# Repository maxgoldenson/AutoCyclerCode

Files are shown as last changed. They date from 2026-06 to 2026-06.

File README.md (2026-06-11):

# AutoCycler

Automated coffee-machine cycler for endurance testing. A Raspberry Pi runs a touchscreen
GUI that drives two ESP32 boards over USB — a **dispenser** (stepper that doses coffee)
and a **front assembly** (color sensors + servo + brew trigger) — to run brew cycles
unattended. The whole stack (Pi app, launcher, and ESP32 firmware) **updates itself
over-the-air from GitHub** — you set a Pi up once, then just push to `main`.

---

## 1. Set up a Pi — one command

On a fresh Raspberry Pi (logged in as your normal user, connected to the internet), open
a Terminal and paste:

```bash
curl -fsSL https://raw.githubusercontent.com/maxgoldenson/AutoCyclerCode/main/pi_install.sh | bash && sudo reboot
```

That installs everything (Python GUI, the ESP32 flashing toolchain, serial access),
deploys the app + launcher + firmware, sets it to start on boot, prints a green
checklist, and reboots. **Plug both ESP32 boards into USB** (before or after — it waits
for them).

After the reboot the app appears, connects to the boards, and flashes them to the latest
firmware automatically (you'll see a live progress screen). That's the whole setup.

> The script is safe to re-run. It works on Raspberry Pi OS Bullseye, Buster, and
> Bookworm. If any line in the checklist shows `[!!]`, just run it again — it's almost
> always a flaky download.

---

## 2. It updates itself

Once a Pi is set up, it polls GitHub (`main`) every minute and updates **on its own** —
you never have to touch the Pi again:

| What | When it updates |
|---|---|
| **App** (`coffee_cycler.py`) | a new version is on `main` → downloads, restarts the app |
| **Launcher** itself | `launcher.py` changed → self-updates and relaunches |
| **ESP32 firmware** | a board's `FW_VERSION` changed → compiles + flashes it (live progress screen), then **reboots the Pi** to bring the board up on the new firmware (the version is recorded first, so it won't loop) |

**Updates never interrupt a running brew series.** While the app is running cycles it
raises a "busy" flag; the launcher defers *all* updates (app, firmware, and the reboot)
until the series finishes, then applies them. If the app crashes mid-run the flag goes
stale and updates resume on their own.

---

## 3. Releasing an update (maintainer)

Everything flows from `main`:

- **App change:** edit `coffee_cycler.py`, push to `main`. Pis pick it up within a minute.
- **Firmware change:** edit the `.ino`, **bump its `#define FW_VERSION`**, push to `main`.
  Pis flash it on the next check.
  - ⚠️ If you change firmware behaviour but *don't* bump `FW_VERSION`, the fleet won't
    flash it. This is intentional — it stops comment/whitespace edits from re-flashing
    every Pi. Bump the version whenever the firmware functionally changes.

`FW_VERSION` lives near the top of each sketch (next to `DEVICE_ID`).

---

## 4. Check what's running

The app header shows all three versions at a glance:

```
BrewBird Auto Cycler   v2026-06-11 16:04   ESP32 fw — DISP 2026-06-10.4 · FRONT 2026-06-10.3
```

Or on the Pi:

```bash
grep '^VERSION' ~/autocycler/coffee_cycler.py    # app version (the GUI header)
cat ~/autocycler/flashed_firmware.json           # firmware version flashed to each board
tail -f ~/autocycler/launcher.log                # live: what the launcher is doing
```

---

## 5. Updating Pis set up before self-update existed (one-time)

Older Pis run a launcher that can't self-update. Bring each one onto the self-updating
launcher **once** — after this it's automatic forever:

```bash
cd ~/autocycler && ok=1; for f in launcher.py bootscript.py flash_splash.py; do curl -fsSL "https://raw.githubusercontent.com/maxgoldenson/AutoCyclerCode/main/$f" -o "/tmp/$f" || ok=0; done; if [ "$ok" = 1 ] && grep -q 'def self_update' /tmp/launcher.py; then mv /tmp/launcher.py /tmp/bootscript.py /tmp/flash_splash.py . && echo "OK — rebooting" && sudo reboot; else echo "FAILED — nothing changed"; fi
```

(Or just re-run the Section 1 installer — it's idempotent.)

---

## 6. Troubleshooting

```bash
tail -30 ~/autocycler/launcher.log     # the launcher logs every decision here
uptime; ps -o pid,etime,cmd -C python3 # is it stable? (not a reboot loop)
```

| Symptom | Likely cause / fix |
|---|---|
| App never updates | No internet, or an old pre-self-update launcher (do Section 5). |
| `version 'GLIBC_2.34' not found` when flashing | ESP32 core 3.x on old Pi OS — the installer pins `esp32:esp32@2.0.17`; re-run it. |
| Board won't connect / `device reports readiness… returned no data` | ModemManager grabbing the port — the installer disables it; re-run it. |
| Header shows `ESP32 fw … ?` for a board | That board is on old firmware without the version query; it updates on the next flash. |
| "Keeps flashing every few minutes" | Either a real `FW_VERSION` bump (one flash, then stops) or an upload is failing — the log line `… needs flashing: version X (on board: Y)` shows which. |
| Screen reboots right after a firmware flash | Expected — the Pi auto-reboots after flashing to reliably bring the boards back online. It records the version first, so it won't loop. (Needs passwordless `sudo`, the Pi default.) |

---

## 7. What's in the repo

| File | Role |
|---|---|
| `coffee_cycler.py` | The Tkinter touchscreen app (runs the brew cycles). |
| `launcher.py` | Boot supervisor: self-update, app update, firmware flashing, app lifecycle. |
| `AUTOCYCLER_DISPENSOR/*.ino` | Dispenser ESP32 firmware (stepper + dispense protocol). |
| `AUTOCYCLER_FRONT/*.ino` | Front-assembly ESP32 firmware (sensors, servo, brew trigger). |
| `flash_splash.py` | Live "updating firmware" progress screen. |
| `bootscript.py` | Thin autostart shim that execs the launcher. |
| `pi_install.sh` | The one-shot installer (Section 1). |
| `PI_SETUP.md` | Detailed/manual setup reference. |
| `.claude/skills/ota/SKILL.md` | OTA system design, operational rules, and gotchas. |

For the OTA architecture and the hard-won gotchas (core pin, ModemManager, onboard-UART,
single-instance, post-flash reset), see `.claude/skills/ota/SKILL.md`.

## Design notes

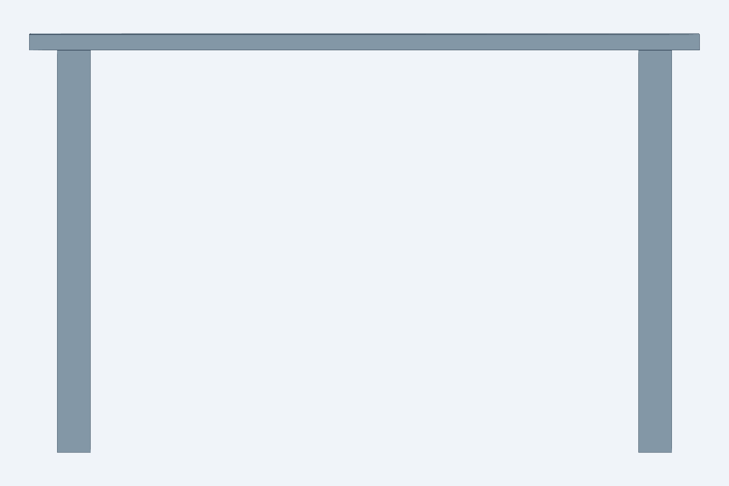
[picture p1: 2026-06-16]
cad/table_front_20260616T002230Z.png

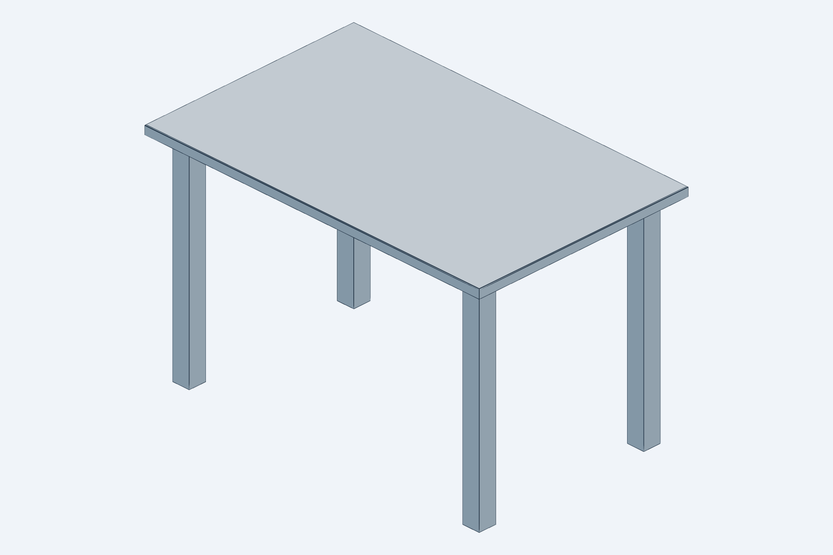
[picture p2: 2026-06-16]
cad/simple_table_20260616T001931Z.png

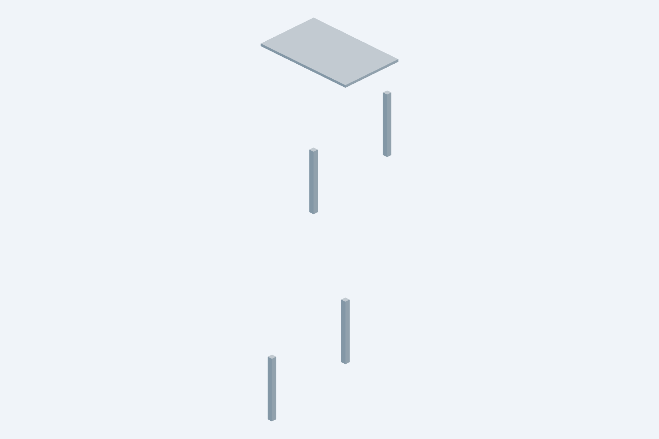
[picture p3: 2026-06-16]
cad/table_exploded_20260616T002232Z.png

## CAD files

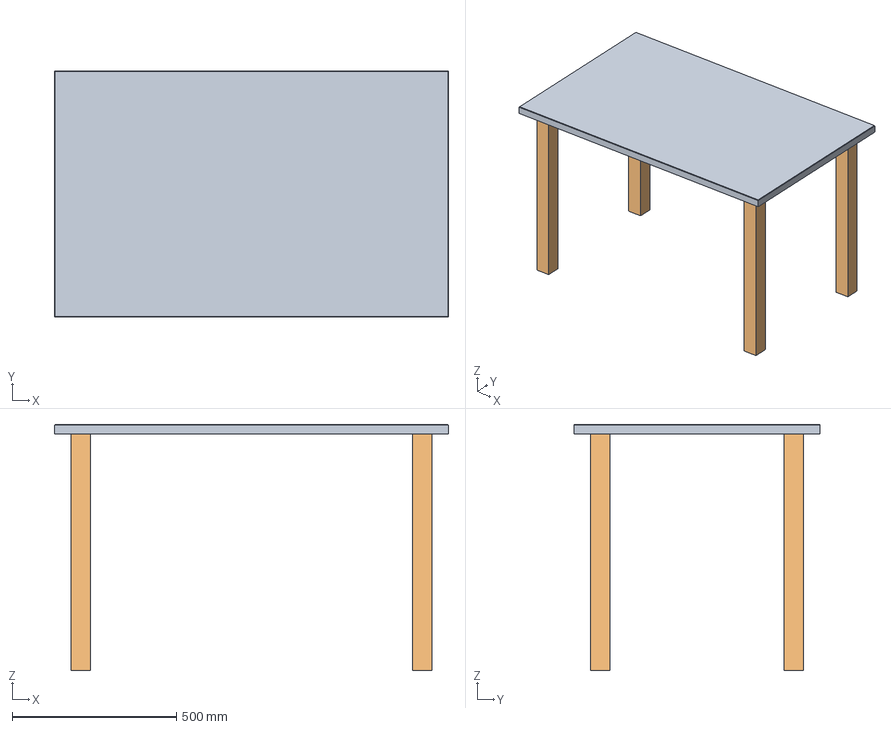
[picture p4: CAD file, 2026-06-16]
cad/simple_table.step
1200.0 x 750.0 x 750.0 mm
tabletop
leg:front_left
leg:front_right
leg:rear_left
leg:rear_right

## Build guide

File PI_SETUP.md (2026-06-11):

# Pi deployment guide — detailed reference

> **New here? Start with [README.md](README.md)** — it has the one-command setup and the
> day-to-day usage. This file is the detailed / manual reference and troubleshooting deep-dive.

## Quick install (recommended)

One script does everything below — toolchain, libraries, code, autostart. Run it on the
Pi as your normal user:

```bash
curl -fsSL https://raw.githubusercontent.com/maxgoldenson/AutoCyclerCode/main/pi_install.sh | bash
sudo reboot
```

It is safe to re-run. Override defaults with env vars, e.g.
`AUTOCYCLER_BRANCH=main ESP32_FQBN=esp32:esp32:esp32doit-devkit-v1 bash pi_install.sh`.
The manual steps below are kept for reference / troubleshooting.

### What it handles for partial / missing devices
- The app UI comes up first and **auto-reconnects** as boards are plugged in — works with
  two, one, or zero modules connected at boot.
- Firmware is flashed **only for boards that are actually connected**. If a module isn't
  plugged in, the launcher waits and flashes it automatically once you connect it.
- A full-screen **"Updating firmware — please wait"** message shows during flashing.

---

This covers the one-time changes on the Raspberry Pi to run the new `launcher.py`
(minute-poll app auto-update + over-the-air ESP32 firmware flashing).

> **Key fact:** `launcher.py` updates `coffee_cycler.py` and the ESP32 firmware, but it
> **does not update itself**. So `launcher.py` and `bootscript.py` must be deployed by
> hand once (Step 1). After that, app and firmware updates are automatic.

Assumes the install lives at `/home/pi/autocycler/` (the default `AUTOCYCLER_DIR`). If
yours is elsewhere, substitute that path and set `AUTOCYCLER_DIR` in the boot env.

---

## Step 1 — Put the new launcher on the Pi

The Pi will poll the **`main`** branch (already baked into the
default; see Step 2 to change it).

```bash
cd /home/pi/autocycler
BRANCH=main
RAW="https://raw.githubusercontent.com/maxgoldenson/AutoCyclerCode/${BRANCH}"

curl -fsSL "${RAW}/launcher.py"   -o launcher.py
curl -fsSL "${RAW}/bootscript.py" -o bootscript.py
```

That's the only manual code copy. On the next boot the launcher will fetch the latest
`coffee_cycler.py` and both `.ino` sketches itself.

---

## Step 2 — Confirm the branch being polled

The default is the feature branch. You don't need to do anything unless you want a
different branch — override it without editing code via an env var:

```bash
# Poll a different branch (e.g. main, once this work is merged):
export AUTOCYCLER_BRANCH=main
```

Set this in the same place your boot launches `launcher.py` (see Step 6) so it persists.
Quick check that the branch is reachable:

```bash
curl -fsS -o /dev/null -w "%{http_code}\n" \
  "https://raw.githubusercontent.com/maxgoldenson/AutoCyclerCode/main/coffee_cycler.py"
# expect: 200
```

---

## Step 3 — Install arduino-cli + ESP32 toolchain (for firmware flashing)

Without this, the app auto-update still works; firmware flashing is just skipped and
retried each minute until the toolchain is present (you'll see a warning in the log).

```bash
# 3a. Install arduino-cli (ARM build auto-detected) straight onto PATH.
# NOTE: the installer drops the binary in ./bin of the CURRENT directory unless you
# set BINDIR — so we force /usr/local/bin to avoid PATH surprises.
curl -fsSL https://raw.githubusercontent.com/arduino/arduino-cli/master/install.sh | sudo BINDIR=/usr/local/bin sh
arduino-cli version    # sanity check (expect 1.5.x)

# If you already ran the installer without BINDIR, the binary is in ./bin of wherever
# you ran it (e.g. /home/pi/autocycler/bin). Just move it onto PATH instead:
#   sudo mv /home/pi/autocycler/bin/arduino-cli /usr/local/bin/

# 3b. Add the ESP32 board package and install the core.
arduino-cli config init
arduino-cli config add board_manager.additional_urls \
  https://espressif.github.io/arduino-esp32/package_esp32_index.json
arduino-cli core update-index

# IMPORTANT — pick the core version for your OS:
#   Raspberry Pi OS Bookworm (glibc >= 2.34): the latest core 3.x works:
#       arduino-cli core install esp32:esp32
#   Raspberry Pi OS Bullseye / Buster (glibc 2.31 / 2.28): the esptool bundled with
#   core 3.x is a frozen binary that needs GLIBC_2.33/2.34 and will fail with
#   "version `GLIBC_2.34' not found". Pin the 2.0.x line, which ships esptool.py as a
#   plain Python script and runs on the Pi's own Python:
#       arduino-cli core install esp32:esp32@2.0.17
# Check your glibc with:  ldd --version | head -1
arduino-cli core install esp32:esp32@2.0.17

# 3c. Install the two libraries the FRONT sketch needs (deps pulled automatically)
arduino-cli lib install "Adafruit TCS34725"
arduino-cli lib install "ESP32Servo"
```

> If your boot process runs `launcher.py` with a minimal `PATH` (e.g. a bare systemd
> unit), either keep `arduino-cli` in `/usr/local/bin` (usually on PATH) or set
> `ARDUINO_CLI=/usr/local/bin/arduino-cli` in the boot env.

---

## Step 4 — Set the board type (FQBN) if needed

The default is the generic `esp32:esp32:esp32`. If your boards are a specific variant,
flashing may fail until you set the right FQBN.

```bash
arduino-cli board listall | grep -i esp32      # find your board's FQBN
# then, in the boot env:
export ESP32_FQBN=esp32:esp32:esp32doit-devkit-v1   # example — use yours
```

---

## Step 5 — Serial port access

The user that runs the launcher must be able to open the ESP32 serial ports (for
WHO-AM-I probing, flashing, and the app itself):

```bash
sudo usermod -aG dialout pi
# log out / back in (or reboot) for the group change to take effect
```

---

## Step 6 — Make the env vars stick, then reboot

Put any `AUTOCYCLER_BRANCH` / `ESP32_FQBN` / `ARDUINO_CLI` overrides where the boot
actually launches `launcher.py`:

- **systemd unit:** add `Environment=AUTOCYCLER_BRANCH=...` lines under `[Service]`,
  then `sudo systemctl daemon-reload`.
- **LXDE autostart / `.bashrc` / `rc.local`:** `export VAR=...` before the
  `python3 .../launcher.py` line.

Then:

```bash
sudo reboot
```

---

## Verify it's working

```bash
tail -f /home/pi/autocycler/launcher.log
```

Expected on first boot:
- `Network ready.`
- `Downloaded new coffee_cycler.py (...)` (if newer than local)
- `Downloaded new firmware source for DISPENSER/FRONT_ASSEMBLY (...)`
- `Identified DISPENSER on /dev/ttyUSB...`, `Compiling ...`, `Uploading ...`,
  `Flashed ... successfully`
- `Launching app.`

Then once a minute it re-checks GitHub and logs only when something changes.

---

## Behaviour notes

- **First boot flashes both ESP32s.** With no flash record yet
  (`flashed_firmware.json` absent), both boards are flashed to the branch's current
  firmware to establish a known-good baseline. After that, only genuine firmware
  changes flash.
- **Failed/skipped flashes retry.** Flashing is gated on a "last successfully flashed"
  record, so a missing toolchain, missing port, or bad compile is retried next cycle —
  it won't silently leave the boards on stale firmware.
- **Updates apply immediately, even mid-cycle.** A new app version restarts the app at
  once; new firmware stops the app, flashes, and restarts. If an update lands during a
  brew it will interrupt that brew. This is safe-ish now (the firmware auto-releases the
  CAP trigger and the dispense is at-most-once), but if you'd rather updates wait for an
  idle moment, that needs a small "busy" signal from the app — ask and it can be added.
- **`launcher.py`/`bootscript.py` don't self-update.** Re-run Step 1 whenever those two
  files change upstream.
- **Switching to `main` after merge:** set `AUTOCYCLER_BRANCH=main` (Step 2/6) and
  re-run Step 1 to pull the merged launcher.

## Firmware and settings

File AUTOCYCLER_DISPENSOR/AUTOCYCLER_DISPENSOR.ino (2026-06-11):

#include <Arduino.h>

// ── Pin config ─────────────────────────────────────────────────────────────────
#define STEP_PIN    25
#define DIR_PIN     33
#define ENABLE_PIN  32

// ── Serial config ──────────────────────────────────────────────────────────────
#define SERIAL_BAUD 115200

// ── Device identity ────────────────────────────────────────────────────────────
#define DEVICE_ID   "DISPENSER"

// ── Firmware version ───────────────────────────────────────────────────────────
// The launcher flashes the board ONLY when this string changes — so editing comments
// or whitespace never triggers a fleet-wide re-flash. Bump it on any FUNCTIONAL change.
#define FW_VERSION  "2026-06-10.4"

// ── Stepper config ─────────────────────────────────────────────────────────────
#define STEPS_PER_REV     (400 * 48 / 20)   // 1.8° motor + gearing
#define MICROSTEPPING     4
#define STEP_DELAY_MICROS 420               // lower = faster

const float STEPS_PER_DEGREE = (STEPS_PER_REV * MICROSTEPPING) / 360.0f;

// ── Safety limits ──────────────────────────────────────────────────────────────
// Reject absurd moves from a garbled command — a normal dispense is 360 deg.
#define MAX_DISPENSE_DEG 1080.0f   // 3 revolutions

// The ANGLE: ack used to be transmitted in the microseconds after the final step pulse,
// while the driver/coils are still switching — motor EMI right on top of the UART frame
// is the prime suspect for the ~50% corrupted/lost acks seen in the field (the FRONT
// board has no motor and never showed the problem). Wait for the transients to die
// before touching the UART.
#define ACK_SETTLE_MS 75

// ── State ──────────────────────────────────────────────────────────────────────
bool motorEnabled = false;
long lastDispenseSeq = -1;     // seq id of the last executed SET ANGLE (at-most-once)
float lastDispenseDeg = 0.0f;  // degrees of that dispense (reported by GET STATUS)
uint32_t bootId = 0;           // random per boot — lets the host detect a mid-move reset

// ── Helpers ───────────────────────────────────────────────────────────────────

void setMotorEnabled(bool enable) {
    motorEnabled = enable;
    digitalWrite(ENABLE_PIN, enable ? LOW : HIGH);  // driver is active-low
}

// Returns true only if s is a valid signed decimal number (e.g. "360", "-12.5").
// Guards against String::toFloat() silently coercing garbage to 0.0.
bool isNumeric(const String &s) {
    if (s.length() == 0) return false;
    int start = (s[0] == '+' || s[0] == '-') ? 1 : 0;
    if (start >= (int)s.length()) return false;
    bool dot = false, digit = false;
    for (int i = start; i < (int)s.length(); i++) {
        char c = s[i];
        if (c == '.') {
            if (dot) return false;   // more than one decimal point
            dot = true;
        } else if (c >= '0' && c <= '9') {
            digit = true;
        } else {
            return false;
        }
    }
    return digit;
}

void stepDegrees(float degrees) {
    if (degrees == 0.0f) return;

    long steps = abs(degrees) * STEPS_PER_DEGREE;
    digitalWrite(DIR_PIN, degrees > 0 ? HIGH : LOW);

    for (long i = 0; i < steps; i++) {
        digitalWrite(STEP_PIN, HIGH);
        delayMicroseconds(STEP_DELAY_MICROS);
        digitalWrite(STEP_PIN, LOW);
        delayMicroseconds(STEP_DELAY_MICROS);

        // This move can run several seconds — past the ~5s ESP32 task watchdog. Without
        // feeding it, the watchdog fires mid-move and dumps warning text onto the serial
        // line, corrupting the ANGLE: reply (the front board never blocks this long, so
        // it never sees this). yield() lets the idle task run and resets the watchdog;
        // it returns in microseconds when nothing else is pending, so step timing is
        // unaffected. Every 64 steps (~50 ms) is far more often than the watchdog needs.
        if ((i & 0x3F) == 0) yield();
    }
}

// ── Command handlers ───────────────────────────────────────────────────────────

void handleWhoAmI() {
    Serial.print("IAM:"); Serial.println(DEVICE_ID);
}

/**
 * SET ANGLE <degrees> [<seq>]
 * Enables motor, moves, then re-disables unless the motor was already
 * held enabled via SET MOTOR ON.
 *
 * <seq> is an optional monotonic id from the host. SET ANGLE is a RELATIVE move,
 * so executing it twice dispenses twice (an overflow hazard). If a command arrives
 * whose seq matches the last one already executed, it is treated as a duplicate
 * (e.g. the host re-sent because an ack was lost, or a frame was buffered during the
 * blocking move) and is ACKed WITHOUT moving — keeping the dispense at-most-once.
 * Commands without a seq are executed normally (backward compatible).
 *
 * Response: ANGLE:<degrees>
 */
void handleSetAngle(const String &args) {
    if (args.length() == 0) {
        Serial.println("ERROR:SET ANGLE requires a value in degrees");
        return;
    }

    // Split an optional trailing sequence id: "<degrees> <seq>".
    String degStr = args;
    long seq = -1;
    int sp = args.indexOf(' ');
    if (sp >= 0) {
        degStr = args.substring(0, sp);
        String seqStr = args.substring(sp + 1);
        seqStr.trim();
        if (seqStr.length() > 0) seq = seqStr.toInt();
    }
    degStr.trim();

    // Reject non-numeric input rather than silently dispensing 0 deg (a dry brew the
    // host would read as success).
    if (!isNumeric(degStr)) {
        Serial.println("ERROR:SET ANGLE value is not numeric");
        return;
    }
    float degrees = degStr.toFloat();

    // Never make an enormous move from a garbled value.
    if (fabs(degrees) > MAX_DISPENSE_DEG) {
        Serial.print("ERROR:SET ANGLE magnitude exceeds limit ");
        Serial.println(MAX_DISPENSE_DEG);
        return;
    }

    // At-most-once: a repeated seq means the host deliberately re-sent because it could
    // not verify execution (lost ack / lost command) — ack WITHOUT moving. Equality only,
    // no time window: the host may legitimately re-send the same seq tens of seconds
    // later (after its STATUS verification probes), and host seqs are session-random +
    // monotonic, so a stale match across sessions is effectively impossible.
    if (seq >= 0 && seq == lastDispenseSeq) {
        Serial.print("ANGLE:"); Serial.println(degrees);
        return;
    }

    bool wasEnabled = motorEnabled;

    setMotorEnabled(true);
    stepDegrees(degrees);
    if (!wasEnabled) setMotorEnabled(false);

    lastDispenseDeg = degrees;
    if (seq >= 0) lastDispenseSeq = seq;

    // Let the motor/driver switching transients die down before transmitting — sending
    // the ack in the same microseconds the coils de-energize is how acks get corrupted.
    delay(ACK_SETTLE_MS);

    Serial.print("ANGLE:"); Serial.println(degrees);
}

/**
 * GET STATUS
 * Idempotent query the host uses to VERIFY a dispense when the ANGLE: ack was lost:
 *   STATUS:<bootId>,<lastSeq>,<lastDeg>
 * - bootId: random per boot. If it changes between two host queries, the board reset
 *   (e.g. brownout mid-move) and any in-flight dispense state is unknowable.
 * - lastSeq: seq of the last executed SET ANGLE (-1 = none since boot).
 * If lastSeq matches what the host sent, the dispense happened and only the ack was
 * lost; if not (same bootId), the command itself was lost and a same-seq re-send is
 * safe (the equality dedup above makes it at-most-once).
 */
void handleGetStatus() {
    Serial.print("STATUS:");
    Serial.print(bootId);
    Serial.print(",");
    Serial.print(lastDispenseSeq);
    Serial.print(",");
    Serial.println(lastDispenseDeg);
}

/**
 * GET VERSION → FW:<FW_VERSION>
 * Lets the host display which firmware is actually running on the board.
 */
void handleGetVersion() {
    Serial.print("FW:");
    Serial.println(FW_VERSION);
}

/**
 * SET MOTOR <ON|OFF>
 * Holds or releases the motor driver enable line independently of moves.
 * Useful for holding position under load or releasing for manual adjustment.
 *
 * Response: MOTOR:ON or MOTOR:OFF
 */
void handleSetMotor(const String &args) {
    if (args.equalsIgnoreCase("ON")) {
        setMotorEnabled(true);
        Serial.println("MOTOR:ON");
    } else if (args.equalsIgnoreCase("OFF")) {
        setMotorEnabled(false);
        Serial.println("MOTOR:OFF");
    } else {
        Serial.println("ERROR:SET MOTOR requires ON or OFF");
    }
}

// ── Command dispatch ───────────────────────────────────────────────────────────

void dispatch(const String &raw) {
    String cmd = raw;
    cmd.trim();
    if (cmd.length() == 0) return;

    int spaceIdx = cmd.indexOf(' ');
    String verb  = (spaceIdx < 0) ? cmd          : cmd.substring(0, spaceIdx);
    String rest  = (spaceIdx < 0) ? String("")    : cmd.substring(spaceIdx + 1);
    rest.trim();
    verb.toUpperCase();

    if (verb == "WHO") {
        String noun = rest;
        noun.toUpperCase();
        if (noun == "AM I") handleWhoAmI();
        else { Serial.print("UNKNOWN:"); Serial.println(cmd); }

    } else if (verb == "GET") {
        String noun = rest;
        noun.toUpperCase();
        if      (noun == "STATUS")  handleGetStatus();
        else if (noun == "VERSION") handleGetVersion();
        else { Serial.print("UNKNOWN:"); Serial.println(cmd); }

    } else if (verb == "SET") {
        int sp2     = rest.indexOf(' ');
        String noun = (sp2 < 0) ? rest            : rest.substring(0, sp2);
        String args = (sp2 < 0) ? String("")       : rest.substring(sp2 + 1);
        noun.toUpperCase(); args.trim();

        if      (noun == "ANGLE") handleSetAngle(args);
        else if (noun == "MOTOR") handleSetMotor(args);
        else { Serial.print("UNKNOWN:"); Serial.println(cmd); }

    } else {
        Serial.print("UNKNOWN:"); Serial.println(cmd);
    }
}

// ── Arduino lifecycle ──────────────────────────────────────────────────────────

void setup() {
    Serial.begin(SERIAL_BAUD);
    while (!Serial) { delay(10); }

    pinMode(STEP_PIN,   OUTPUT);
    pinMode(DIR_PIN,    OUTPUT);
    pinMode(ENABLE_PIN, OUTPUT);

    setMotorEnabled(false);  // driver disabled at startup

    // Random per-boot id (esp_random uses the hardware RNG). 0 is reserved for
    // "unknown", so nudge it if the RNG ever returns 0.
    bootId = (uint32_t)esp_random();
    if (bootId == 0) bootId = 1;

    Serial.print("READY:"); Serial.println(DEVICE_ID);
}

void loop() {
    if (Serial.available()) {
        String line = Serial.readStringUntil('\n');
        dispatch(line);
    }
}

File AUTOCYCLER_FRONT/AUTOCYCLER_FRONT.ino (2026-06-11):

/*
 * FRONT ASSEMBLY — Serial Command Reference
 * ──────────────────────────────────────────────────────────────────────────────
 *  WHO AM I               → IAM:FRONT_ASSEMBLY
 *
 *  GET COLOR ERROR        → RGB:<r>,<g>,<b>   (Error sensor, MUX ch 1)
 *  GET COLOR RING         → RGB:<r>,<g>,<b>   (Ring sensor,  MUX ch 0)
 *  GET COLOR ERROR LED    → RGB:...  (keeps LED on after read)
 *  GET COLOR RING  LED    → RGB:...  (keeps LED on after read)
 *
 *  SET SERVO <0-180>      → SERVO:<angle>
 *  SET CAP ON             → CAP:ON
 *  SET CAP OFF            → CAP:OFF
 *
 *  On boot:               READY:FRONT_ASSEMBLY
 *  On error:              ERROR:<message>
 * ──────────────────────────────────────────────────────────────────────────────
 */

#include <Wire.h>
#include <Adafruit_TCS34725.h>
#include <ESP32Servo.h>

// ── Pin config ─────────────────────────────────────────────────────────────────
#define LED_PIN 25
#define SERVO_PIN 32
#define CAP_PIN 33

// ── Serial config ──────────────────────────────────────────────────────────────
#define SERIAL_BAUD 115200

// ── Device identity ────────────────────────────────────────────────────────────
#define DEVICE_ID "FRONT_ASSEMBLY"

// ── Firmware version ───────────────────────────────────────────────────────────
// The launcher flashes the board ONLY when this string changes — so editing comments
// or whitespace never triggers a fleet-wide re-flash. Bump it on any FUNCTIONAL change.
#define FW_VERSION "2026-06-10.3"

// ── MUX config ─────────────────────────────────────────────────────────────────
#define PCA9548A_ADDR 0x70
#define MUX_CH_RING 0   // Channel 0 = Ring sensor
#define MUX_CH_ERROR 1  // Channel 1 = Error sensor

// ── Sensor config ──────────────────────────────────────────────────────────────
// Single instance used for both sensors — MUX channel is selected before each access.
Adafruit_TCS34725 tcs = Adafruit_TCS34725(
  TCS34725_INTEGRATIONTIME_50MS,
  TCS34725_GAIN_4X);

Servo myServo;

// ── Safety / failsafe config ────────────────────────────────────────────────────
// If the host ever fails to release the brew trigger (crash, USB unplug, killed
// process), auto-release CAP after this long so the machine's start button can never
// be held pressed indefinitely. Set well above the longest legitimate hold — the
// host's 10s reset hold — so a real operation is never cut short.
#define CAP_MAX_ON_MS 15000UL
#define SERVO_REST_DEG 95   // safe "gate closed" position to assume on boot

// ── State ──────────────────────────────────────────────────────────────────────
bool capActive = false;
unsigned long capOnMillis = 0;   // millis() at the moment CAP was last asserted

// ── Helpers ───────────────────────────────────────────────────────────────────

void selectMuxChannel(uint8_t ch) {
  Wire.beginTransmission(PCA9548A_ADDR);
  Wire.write(1 << ch);
  Wire.endTransmission();
}

bool readRGB(uint8_t channel, uint8_t &r, uint8_t &g, uint8_t &b) {
  selectMuxChannel(channel);
  uint16_t raw_r, raw_g, raw_b, raw_c;
  tcs.getRawData(&raw_r, &raw_g, &raw_b, &raw_c);
  if (raw_c == 0) return false;
  r = (uint8_t)constrain((raw_r * 255UL) / raw_c, 0, 255);
  g = (uint8_t)constrain((raw_g * 255UL) / raw_c, 0, 255);
  b = (uint8_t)constrain((raw_b * 255UL) / raw_c, 0, 255);
  return true;
}

void setCapPin(bool active) {
  capActive = active;
  if (active) {
    capOnMillis = millis();   // start the auto-release watchdog
    pinMode(CAP_PIN, OUTPUT);
    digitalWrite(CAP_PIN, LOW);
  } else {
    pinMode(CAP_PIN, INPUT);
  }
}

// ── Command handlers ───────────────────────────────────────────────────────────

void handleWhoAmI() {
  Serial.print("IAM:");
  Serial.println(DEVICE_ID);
}

// GET VERSION → FW:<FW_VERSION>  — lets the host show which firmware is running.
void handleGetVersion() {
  Serial.print("FW:");
  Serial.println(FW_VERSION);
}

void handleGetColor(const String &args) {
  // Syntax: GET COLOR [ERROR|RING] [LED]
  // Sensor defaults to ERROR for backward compatibility.
  String upper = args;
  upper.toUpperCase();
  upper.trim();

  uint8_t channel = MUX_CH_ERROR;
  bool ledArg = false;

  if (upper.startsWith("RING")) {
    channel = MUX_CH_RING;
    String tail = upper.substring(4);
    tail.trim();
    ledArg = (tail == "LED");
  } else if (upper.startsWith("ERROR")) {
    channel = MUX_CH_ERROR;
    String tail = upper.substring(5);
    tail.trim();
    ledArg = (tail == "LED");
  } else {
    ledArg = (upper == "LED");
  }

  digitalWrite(LED_PIN, HIGH);
  delay(60);

  uint8_t r, g, b;
  if (readRGB(channel, r, g, b)) {
    Serial.print("RGB:");
    Serial.print(r);
    Serial.print(",");
    Serial.print(g);
    Serial.print(",");
    Serial.println(b);
  } else {
    Serial.println("ERROR:zero clear channel");
  }

  if (!ledArg) digitalWrite(LED_PIN, LOW);
}

void handleSetServo(const String &args) {
  if (args.length() == 0) {
    Serial.println("ERROR:SET SERVO requires an angle");
    return;
  }
  int angle = constrain(args.toInt(), 0, 180);
  myServo.write(angle);
  Serial.print("SERVO:");
  Serial.println(angle);
}

void handleSetCap(const String &args) {
  if (args.equalsIgnoreCase("ON")) {
    setCapPin(true);
    Serial.println("CAP:ON");
  } else if (args.equalsIgnoreCase("OFF")) {
    setCapPin(false);
    Serial.println("CAP:OFF");
  } else {
    Serial.println("ERROR:SET CAP requires ON or OFF");
  }
}

// ── Command dispatch ───────────────────────────────────────────────────────────

void dispatch(const String &raw) {
  String cmd = raw;
  cmd.trim();
  if (cmd.length() == 0) return;

  int spaceIdx = cmd.indexOf(' ');
  String verb = (spaceIdx < 0) ? cmd : cmd.substring(0, spaceIdx);
  String rest = (spaceIdx < 0) ? String("") : cmd.substring(spaceIdx + 1);
  rest.trim();
  verb.toUpperCase();

  if (verb == "WHO") {
    String noun = rest;
    noun.toUpperCase();
    if (noun == "AM I") handleWhoAmI();
    else {
      Serial.print("UNKNOWN:");
      Serial.println(cmd);
    }

  } else if (verb == "GET") {
    int sp2 = rest.indexOf(' ');
    String noun = (sp2 < 0) ? rest : rest.substring(0, sp2);
    String args = (sp2 < 0) ? String("") : rest.substring(sp2 + 1);
    noun.toUpperCase();
    args.trim();

    if (noun == "COLOR") handleGetColor(args);
    else if (noun == "VERSION") handleGetVersion();
    else {
      Serial.print("UNKNOWN:");
      Serial.println(cmd);
    }

  } else if (verb == "SET") {
    int sp2 = rest.indexOf(' ');
    String noun = (sp2 < 0) ? rest : rest.substring(0, sp2);
    String args = (sp2 < 0) ? String("") : rest.substring(sp2 + 1);
    noun.toUpperCase();
    args.trim();

    if (noun == "SERVO") handleSetServo(args);
    else if (noun == "CAP") handleSetCap(args);
    else {
      Serial.print("UNKNOWN:");
      Serial.println(cmd);
    }

  } else {
    Serial.print("UNKNOWN:");
    Serial.println(cmd);
  }
}

// ── Arduino lifecycle ──────────────────────────────────────────────────────────
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

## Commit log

2026-06-10 Fix duplicate dispense and harden cycle state machine
    Root cause of the "dispensed three times" failure: SerialDevice.send()
    retried commands by re-writing them verbatim, and SET ANGLE is a RELATIVE
    move — so a lost/garbled ack made the retry loop re-issue the dispense up to
    three times, over-dispensing and risking machine overflow.
    Dispense (primary fix):
    - Add SerialDevice.dispense(): one-shot, NEVER retried. A lost ack aborts the
    cycle (fail-safe) instead of re-sending. Tags each move with a monotonic seq.
    - DISPENSER firmware: at-most-once SET ANGLE <deg> [<seq>] — a duplicate seq
    within a short window (retry / RX-buffered frame) is re-acked without moving.
    Reject non-numeric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
    [AUTOCYCLER_DISPENSOR.ino, AUTOCYCLER_FRONT.ino, coffee_cycler.py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]
2026-06-10 Pi launcher: minute-poll app auto-update + OTA ESP32 firmware flashing
    launcher.py becomes the single boot supervisor:
    - Waits for network, then runs the app and supervises it (relaunch if it exits).
    - Every 60s while booted, checks GitHub for a new coffee_cycler.py; on change it
    downloads and restarts the app immediately (no reboot needed).
    - Watches both ESP32 sketches; on change it stops the app to free the serial
    ports, identifies each board via WHO AM I, compiles from source and flashes with
    arduino-cli, then restarts the app.
    Firmware flashing is gated on a "last successfully flashed" record
    (flashed_firmware.json), not on the local .ino, so a failed/skipped flash (missing
    toolc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
    [bootscript.py, launcher.py, test_launcher_update.py]
2026-06-10 Point Pi launcher at the feature branch; add Pi setup guide
    - launcher.py: GITHUB_BRANCH now defaults to claude/wonderful-allen-o1258o and is
    overridable via AUTOCYCLER_BRANCH (set to main after merge). raw.githubusercontent.com
    resolves the slash branch (verified HTTP 200).
    - Add PI_SETUP.md: step-by-step Pi changes — deploy launcher.py/bootscript.py (which do
    not self-update), confirm the polled branch, install arduino-cli + ESP32 core + libs,
    set FQBN, grant dialout access, persist env vars, reboot, and verify via the log.
    https://claude.ai/code/session_01XNE9Eu3TAsAAnvHJR71RCB
    [launcher.py]
2026-06-10 PI_SETUP: install arduino-cli to /usr/local/bin via BINDIR (CWD-independent)
    The installer drops the binary in ./bin of the current dir; forcing BINDIR avoids the
    PATH mismatch, with a fallback note to move an already-installed binary.
    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
2026-06-10 PI_SETUP: pin esp32 core to 2.0.17 on older Pi OS (glibc < 2.33)
    The esptool bundled with esp32 core 3.x is a frozen binary requiring GLIBC_2.33/2.34,
    which fails on Bullseye/Buster. Core 2.0.x ships esptool.py (plain Python) and runs on
    the Pi's own interpreter. Bookworm can still use core 3.x.
    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
2026-06-10 launcher: bring UI up first, never crash-loop, flash without hanging
    Fixes a black-screen/crash-loop on the Pi: the old flow ran the first-boot firmware
    flash (compile + upload of both boards) BEFORE starting the app, so the screen stayed
    black for minutes; any error restarted main(), and each restart spawned another app
    that fought over the serial ports ("multiple access on port" probe failures).
    - main(): launch the app FIRST so the UI is never black; wait for the network only on a
    fresh install with no app on disk. The supervise loop now catches all exceptions and
    never exits, so a transient error can't become a restart loop.
    - Network checks in the loop use a fast single probe (_net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
    [launcher.py, test_launcher_update.py]
2026-06-10 Tolerate missing/partial devices; add one-shot Pi install script
    Launcher (flash_boards):
    - If no USB serial module is present, do NOT stop the app or compile — log/record a
    "waiting for the module(s) to be connected" status and retry; flashing starts
    automatically once a device appears.
    - Flash only boards that are actually detected; a changed-but-absent board is deferred
    with a clear "waiting for <board>" note while the present one is flashed.
    - Throttle by USB topology so the app isn't disrupted every minute while waiting (retry
    on a plug/unplug event or after a backoff).
    - Show a fullscreen "Updating firmware — please wait" splash (flash_splash.py) during
    the upload window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
    [coffee_cycler.py, flash_splash.py, launcher.py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]
2026-06-10 Fix multiple-instance serial contention (garbled comms / wedged flash)
    Root cause of the wedged flash: two python processes were holding /dev/ttyUSB0 at once
    (duplicate launcher/app instances from the earlier crash-loop debugging + likely a
    duplicate autostart), so WHO AM I came back as garbage and the probe never resolved.
    - launcher: single-instance flock (acquire_single_instance) so only one launcher ever
    runs; a duplicate backs off and exits instead of spawning a competing app.
    - launcher: kill_stray_apps() on startup and before each flash, so an orphan
    coffee_cycler.py can't keep a port open.
    - launcher: open probe ports with exclusive=True — concurrent access now fails fast
    (c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
    [coffee_cycler.py, launcher.py]
2026-06-10 Force-free serial ports before flashing; disable ModemManager
    The flash stalled after "Identified ..." because another process still held the second
    port — the classic pyserial "device reports readiness to read but returned no data" is
    ModemManager probing the USB-serial devices with AT commands.
    - launcher: free_serial_ports() runs `fuser -k` on the ports before probing/uploading,
    SIGKILLing any holder (stray app, duplicate, ModemManager) so the probe/upload never
    fights for the port.
    - pi_install.sh: disable ModemManager (the boards aren't modems) and install psmisc
    (provides fuser).
    Tests: launcher 7/7, dispense 6/6.
    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
    [launcher.py]
2026-06-10 Fix probe hang on the Pi onboard UART; don't halt FRONT on sensor fail
    The flash froze after "Identified DISPENSER" because _probe_ports opened EVERY port
    comports() returned, including the Pi's onboard UART (/dev/ttyAMA0 or /dev/serial0),
    whose open() blocks forever (it backs the console/Bluetooth). The app never hit this
    because its discovery tries the saved ttyUSB ports first.
    - launcher _probe_ports: only probe USB-serial ports (ttyUSB*/ttyACM*), and hard-cap
    each probe with a SIGALRM timeout so no port can ever freeze the launcher again. Also
    log non-replies/unknown ids instead of silence.
    - app discovery: skip the onboard UART when scanning all ports (blacklist ttyAMA*/ttyS*/
    se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
    [AUTOCYCLER_FRONT.ino, coffee_cycler.py, launcher.py]
2026-06-10 Flash an unidentified-but-present board by inference (halted firmware)
    A board whose current firmware is halted won't answer WHO AM I, so it could never be
    auto-flashed to the fixed firmware. If exactly one changed board is unidentified and
    exactly one USB-serial port is unclaimed, pair them and flash — unambiguous on a
    two-board rig, and safe because any board that answered is already claimed (can't
    misroute). This lets a halted FRONT board recover automatically on the next flash.
    Test: launcher 8/8 (adds the inference case), dispense 6/6.
    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
    [launcher.py, test_launcher_update.py]
2026-06-10 Dispense: continue the cycle on a missing ack instead of aborting
    The dispense is sent exactly once and never retried, so a missing/garbled ack cannot
    cause a second dispense (overflow). Aborting the whole run on a transient serial hiccup
    was over-conservative — now the cycle continues (worst case: one under-dosed cup). The
    ack wait (~15s, far above the 3.2s move) still elapses first, so the move has completed
    before we proceed.
    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
    [coffee_cycler.py]
2026-06-10 Dispenser: feed the watchdog during the stepper move (fixes corrupted ANGLE: reply)
    The ~3.2-8s SET ANGLE move is a tight busy-loop with no yield, so a long move blows past
    the ESP32 ~5s task watchdog. When the watchdog trips it dumps warning text onto the same
    UART, right where the ANGLE: ack is sent — corrupting/losing the reply. The front board
    never blocks this long, which is why only the dispenser showed the "lost data on the OK"
    symptom.
    Fix: yield() every 64 steps so the idle task runs and the watchdog stays fed. yield()
    returns in microseconds when idle, so step timing is unaffected. No baud change needed.
    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
    [AUTOCYCLER_DISPENSOR.ino]
2026-06-10 Exactly-once dispense with STATUS verification (fixes lost-ack miscommunication)
    Field data: ~50% of dispense acks were corrupted/lost, dispenser only. Audit findings:
    - The earlier watchdog theory was likely wrong (the ESP32 TWDT doesn't watch loopTask
    on core 1 in the Arduino 2.x core), which matches the yield() fix not helping.
    - Prime suspect: the ANGLE: ack was transmitted in the microseconds after the final
    step pulse, inside the motor/driver switching transients — the FRONT board has no
    motor and never showed the problem.
    - Architectural gap: the protocol had no way to VERIFY execution, so a lost command
    (under-dose) and a lost ack (harmless) were indistinguishable.
    Firmwar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
    [AUTOCYCLER_DISPENSOR.ino, coffee_cycler.py, test_dispense_safety.py]
2026-06-11 Gate firmware flashing on FW_VERSION, not md5 (stop spurious re-flashes)
    Every byte change to a .ino (even a comment) changed its md5 and forced a fleet-wide
    re-flash, which stops the app for a minute and disrupts cycles. Now each sketch carries
    #define FW_VERSION "..." and the launcher flashes ONLY when that string changes; a
    sketch with no FW_VERSION falls back to md5 (old behaviour). The local .ino is still
    refreshed on any byte change so arduino-cli compiles the latest source — only the FLASH
    decision is version-gated. flashed_firmware.json now records the flashed version per
    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
2026-06-11 Launcher self-update so the whole system auto-updates from main
    The launcher updated coffee_cycler.py + firmware but not ITSELF, so launcher.py changes
    (like the new FW_VERSION gating) needed a manual redeploy to every Pi. Now each update
    cycle also pulls launcher.py: if it differs, syntax-check it, write it, stop the app,
    release the single-instance lock, and os.execv into the new launcher (its kill_stray_apps
    + fresh app.start take over). A push that won't even parse is rejected, so a bad commit
    can't brick the fleet. flash_splash.py and bootscript.py are refreshed alongside.
    One-time bootstrap: existing Pis must get this launcher once (re-run pi_install.sh or
    curl launcher.py); after tha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
    [launcher.py, test_launcher_update.py]
2026-06-11 Add OTA skill documenting the self-updating Pi + ESP32 flash system
    Captures the architecture (launcher self-update -> app update -> FW_VERSION-gated
    firmware flash), the operational rules (bump FW_VERSION on functional changes, push to
    main, one-time bootstrap), the hard-won gotchas (esp32 core 2.0.17 glibc pin, disable
    ModemManager, never open the onboard UART, single-instance + exclusive ports), key files,
    and a troubleshooting cheatsheet — so future work on the OTA system doesn't regress them.
    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
2026-06-11 Show live flash progress + firmware versions to the operator
    Flash splash is now a LIVE progress screen, not a static "please wait": flash_splash.py
    renders a progress file the launcher updates as it works, so the operator sees each step
    (compiling -> detecting -> flashing each board) and a final summary listing the flashed
    versions, held on screen for a few seconds before the app returns.
    App header now shows each ESP32's running firmware version next to the app version:
    both boards gain GET VERSION -> FW:<FW_VERSION>, the app queries them after discovery
    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
2026-06-11 Reset ESP32 into run mode after flashing (fix "board offline until reboot")
    Root cause: after arduino-cli/esptool writes flash, the post-flash hard_reset wasn't
    reliably booting the board out of the download bootloader into run mode, so it never
    ran the new firmware or answered WHO AM I until a reboot re-toggled its reset lines.
    The app deliberately never touches DTR/RTS (dsrdtr=False, to avoid spurious resets in
    normal operation), so it couldn't kick the board out of the bootloader on reconnect.
    Fix: after each successful upload the launcher pulses the board's reset into run mode
    (esptool's classic reset: DTR de-asserted = GPIO0 high = run, then pulse RTS = EN), so
    the new firmware starts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
    [launcher.py]
2026-06-11 Add friendly README; make the installer more foolproof + self-checking
    README.md is the new front door: one-command setup, "it updates itself" explanation,
    how to release updates (bump FW_VERSION), how to check versions, the one-time bootstrap
    for old Pis, and a troubleshooting table — all reflecting the current system.
    pi_install.sh: refuse to run as root (would install to the wrong user), default the dir
    to $HOME/autocycler so it works for any username, persist AUTOCYCLER_DIR/BRANCH/FQBN into
    the autostart entry, and end with a green/red checklist that verifies arduino-cli, the
    ESP32 core, both libraries, all deployed files, ModemManager disabled, and dialout access
    — so a non-expert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
2026-06-11 Reboot the Pi after flashing (reliable board recovery) + fix leaked serial lock
    The ESP32 auto-reset after arduino-cli upload isn't dependable on this hardware, so a
    freshly-flashed board can sit in the bootloader and never reconnect until a reboot.
    Replaced the unreliable DTR/RTS reset with the known-good fix: after a successful flash
    the launcher reboots the Pi. Loop-safe — the new FW_VERSION is recorded (os.sync) BEFORE
    the reboot, so the post-reboot check finds nothing to flash. Reboot only fires when
    supervising a real app (app is not None), never in tests/headless; needs passwordless
    sudo (Pi default). The splash shows "Rebooting to bring the boards online…".
    Audit fix (separate l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
    [coffee_cycler.py, launcher.py, test_launcher_update.py]
2026-06-11 Defer all OTA updates while a cycle series is running
    Updates (app restart, firmware flash, launcher self-update re-exec, and the post-flash
    reboot) must never interrupt a brew series. The app now keeps a heartbeat file
    (app_busy) fresh while cycle_thread is alive (written at run start, refreshed every ~3s
    in _tick, removed on run end), and the launcher checks it at the top of _apply_updates:
    if fresh, it skips the whole update cycle and retries next minute. A stale marker (app
    crashed mid-run) is ignored after BUSY_STALE_S (30s) so updates resume on their own; a
    restarted app also clears the marker on init.
    Tests: launcher 13/13 (adds defer-while-busy + stale-marker-ignored), dispense 11/1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
    [coffee_cycler.py, launcher.py, test_launcher_update.py]
2026-06-11 Park the gate OPEN when idle/done
    The gate's resting position is now OPEN (SERVO_OPEN) whenever the machine is idle or a
    run has finished, instead of closed (SERVO_REST). The app opens the gate on connect
    (_discovery_worker) and on a clean run end / user stop (_on_finished). During an active
    run the gate is still managed normally — closed between cycles (run_one's _safe_hardware
    safe state), opened briefly to drop the dose.
    Per request, the gate is NOT opened on _on_error (the board may be in an unknown state),
    so error exits leave it in the safe closed position.
    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
    [coffee_cycler.py]
2026-06-11 Add CAD skills library from earthtojake/text-to-cad
    Vendor all 11 skills (cad, cad-viewer, dxf, urdf, srdf, sdf, gcode,
    bambu-labs, sendcutsend, step-parts, implicit-cad) into .claude/skills
    so they load as project skills in Claude Code sessions.
    https://claude.ai/code/session_01MobgNmPJfU6EpBu26UbZLF
2026-06-16 Add simple table CAD model generated by cad skill
    Four-legged rectangular table (1200x750x30 mm top, 60x60 mm legs,
    750 mm height) authored as a labeled build123d assembly via
    cadpy AssemblyHelper, with the generated STEP and an isometric snapshot.
    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
    [simple_table.step]
2026-06-16 Ignore Python egg-info and generated cad .glb sidecars
    These are build/derived artifacts (editable-install metadata and the
    cad skill's hidden GLB/topology sidecars), not source.
    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
